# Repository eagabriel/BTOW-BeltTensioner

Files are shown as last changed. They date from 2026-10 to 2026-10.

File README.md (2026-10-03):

# BTOW — Belt Tensioner for iRacing

BTOW turns iRacing acceleration telemetry into independent torque commands for two belts. I built it around two BLDC motors, MT6701 encoders, a modified hoverboard controller and a PC application. The GitHub repository is named BTOW-BeltTensioner.

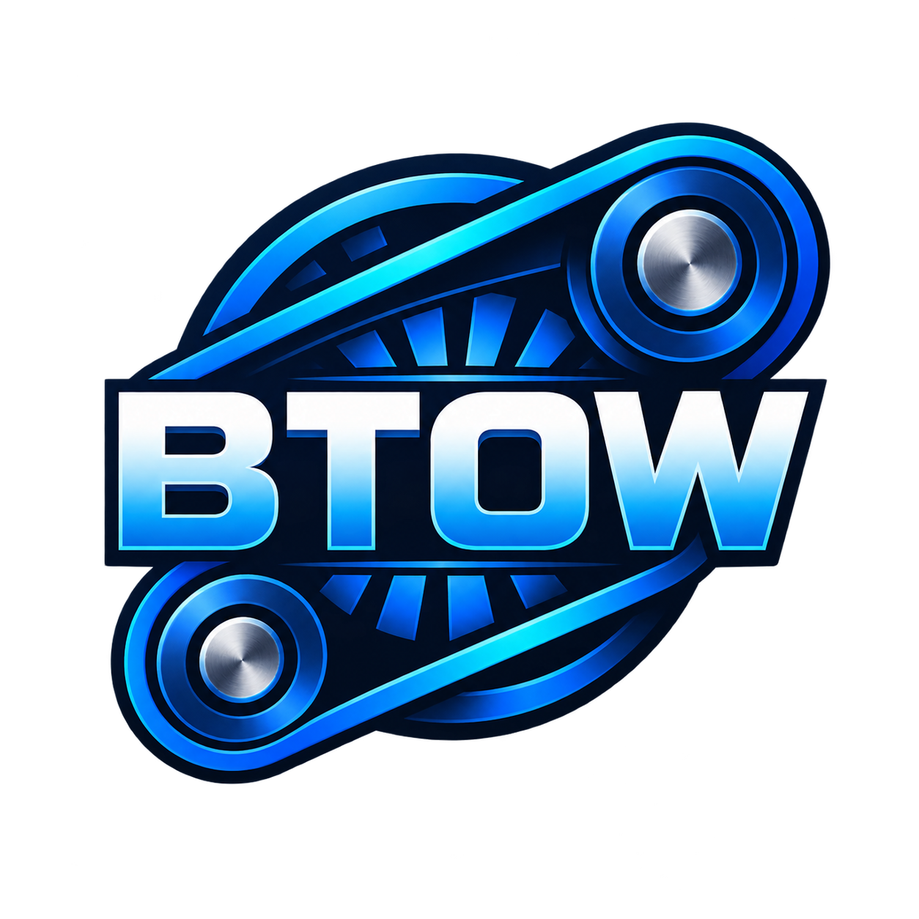
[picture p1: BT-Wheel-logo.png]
BT-Wheel


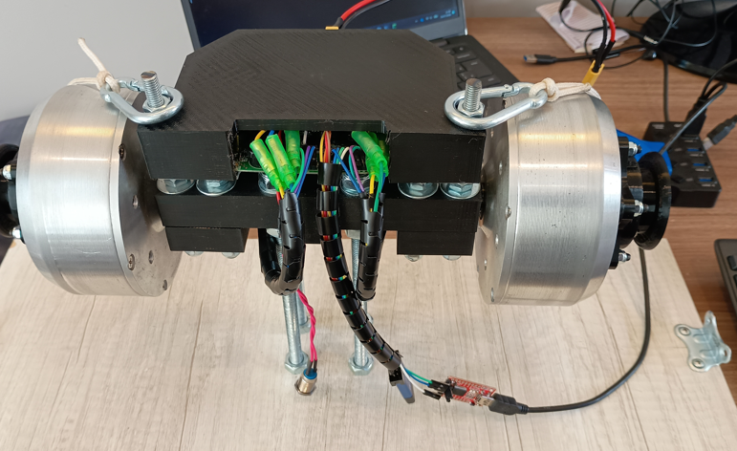
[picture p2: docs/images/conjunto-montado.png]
My assembled BT-Wheel with motors and printed supports


This is my assembly with 3D-printed supports and a cover. Follow the [build and setup tutorial](docs/TUTORIAL.md) for wiring, resistor modifications and software setup. Wire colors in the photos are not a wiring standard.

BT-Wheel is an experimental project, not a certified restraint device. Provide an accessible manual belt release and a physical stop. Software protections do not guarantee release in every failure.

## Belt tensioner in action

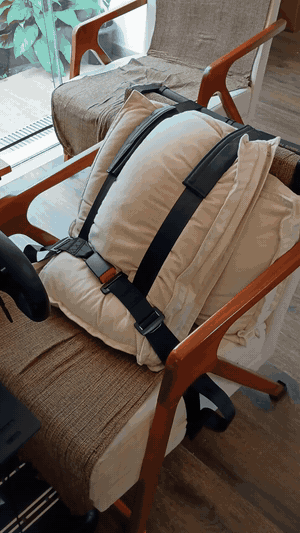
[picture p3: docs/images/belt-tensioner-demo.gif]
BT-Wheel belt tensioner operating — animated demonstration


Watch my belt tensioner operating: [download the demonstration video](https://raw.githubusercontent.com/eagabriel/BTOW-BeltTensioner/refs/heads/main/docs/images/belt-tensioner-demo.mp4) (MP4, approximately 48 MB). Open the downloaded file in your video player; GitHub's file page does not provide inline playback for this video.

## How it works

```text
iRacing → Python / pyirsdk → G mapping → WebSocket → dashboard
                                                      ↓ USB–UART
                            motors ← FOC firmware ← torque commands
```

The backend reads telemetry and calculates torque. The dashboard sends commands through the Web Serial API. The firmware controls current, reads encoders and enforces local limits. Use ST-Link to flash/debug the firmware and a separate USB–UART adapter for PC communication.

Braking adds tension to both belts. Lateral acceleration adds tension to the corresponding side. The vertical effect uses the magnitude of gravity-compensated vertical acceleration. Pretension maintains base tension. Transient belt loosening during acceleration is not implemented.

## Project components

| Component | Purpose |
| --- | --- |
| Python application | Read iRacing, calculate torque and serve the local interface |
| HTML/JavaScript dashboard | Settings, graphs, synthetic tests and serial communication |
| MCU firmware | Dual FOC control, MT6701 feedback, limits and command deadman |
| Compatible hoverboard board | Power stages and current sensing |
| Two BLDC motors and MT6701 encoders | Independent belt actuation |
| Pulleys, belts and frame | Mechanical force transmission |
| Supply and regeneration handling | Supply energy and manage overvoltage |

## Software features

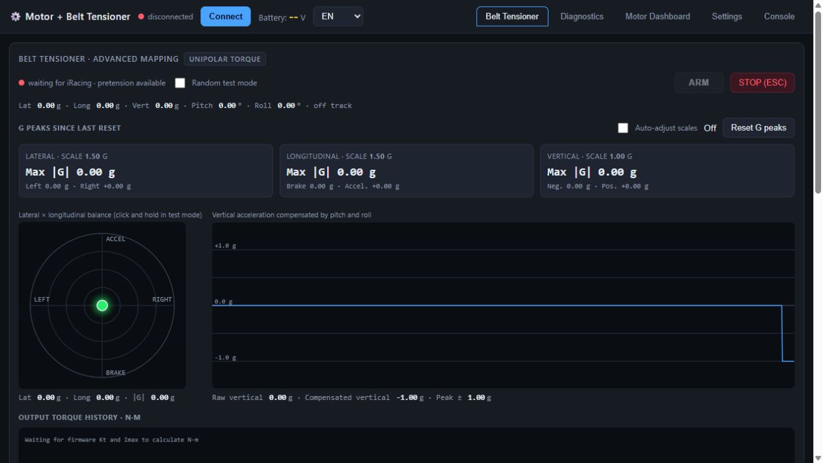
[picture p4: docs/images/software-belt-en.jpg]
BT-Wheel PC dashboard


Select English or Portuguese in the header. Hover over controls for explanations. The [tutorial](docs/TUTORIAL.md) includes real screenshots of settings, motors, diagnostics and the console. Missing readings are expected with serial disconnected.

- Pretension, lateral, longitudinal braking and vertical effects.
- Pitch/roll gravity compensation, dead zones, curves and EMA smoothing.
- Manual/automatic G scales and resettable peak-G tracking.
- Independent attenuation from 100% to 50%, in 1% steps.
- G-ball, vertical history and torque-command history in N·m.
- Automatic JSON settings persistence and separate JSON export/import for motor and belt profiles; board parameters and calibration saved separately in flash.
- Motor dashboard and serial console.
- Individual/bilateral step diagnostics, RAM capture and CSV export.
- MT6701-based RPM limiting and firmware command deadman.

Torque readings are estimates. Command conversion uses `Kt × Imax`; measured current estimates electromagnetic torque. Neither directly measures belt force. Validate belt pull mechanically, accounting for friction, pulley radius and calibration.

## Getting started

Read the [build, installation and usage tutorial](docs/TUTORIAL.md) and the [serial protocol](docs/PROTOCOLO_SERIAL.md).

My working motor and telemetry-effect profiles are included in [profiles/](profiles/). Follow the [profile import instructions](docs/TUTORIAL.md#my-working-example-profiles) and review every hardware limit before using them; they are examples from my assembly, not universal safe defaults.

### Windows executable — no Python required

Open `BTOW.exe` from a compiled distribution. It starts the local server and desktop window, which requires Microsoft Edge WebView2 Runtime. For browser serial access, open `http://127.0.0.1:8000` in Chrome or Edge and keep the executable running. Run only one server instance.

The local build produces `pc-software/dist/BTOW.exe`. Older builds used the name `HoverBelt.exe`. See [GitHub Releases](https://github.com/eagabriel/BTOW-BeltTensioner/releases) for published artifacts. The PC executable does not flash the controller; use ST-Link separately.

Existing settings remain in `%LOCALAPPDATA%\HoverBelt` for compatibility. Use `BTOW_CONFIG_DIR` to override the folder; the older `HOVERBELT_CONFIG_DIR` variable is still supported.

### Python source

Install Python 3.10+ and run from the repository root:

```powershell
cd pc-software
python -m venv .venv
.\.venv\Scripts\python.exe -m pip install -r requirements.txt
.\.venv\Scripts\python.exe run.py
```

Open `http://127.0.0.1:8000` in desktop Chrome or Edge. Serial requires Web Serial API support. The server listens only on the local computer.

To open, build and flash the firmware in **VS Code with PlatformIO IDE**, follow tutorial section 4. Synthetic test mode can move motors when connected and armed.

## Folder layout

```text
BTOW-BeltTensioner/
  pc-software/
    backend/             telemetry, mapping, server and JSON persistence
    frontend/            main dashboard and profile import/export
    assets/              application resources
    tests/               application checks
    app.py               pywebview desktop entry point
    run.py               browser server entry point
    requirements.txt     Python dependencies
    run*.bat             launch scripts
    build*.bat           executable build scripts
  docs/                  tutorial, protocol and images
  firmware/              controller source, drivers and build configuration
    Inc/                 configuration and headers
    Src/                 control loops and drivers
    platformio.ini       TWO_AXIS_VARIANT environment
  mt6701-programmer/      Arduino Pro Micro encoder configuration tool
  Mechanical/            FreeCAD assembly and printed-part designs
  profiles/              working example motor and telemetry-effect JSONs
```

The PC application is contained in `pc-software/`. Launch `run.bat` there, and use `build.bat` or `build-debug.bat` there to package it. Synthetic test mode is available inside the dashboard. Open `firmware/` or `mt6701-programmer/` separately in PlatformIO; each has its own build configuration. Generated caches and executables are excluded from source control.

## Safety and limitations

The firmware requires renewal of `T/TX/TY` within 150 ms; the dashboard has a 250 ms telemetry watchdog. These mechanisms reduce torque in some failures but cannot guarantee mechanical release during every lockup.

Board-temperature monitoring and the dedicated emergency-stop input exist in the code but are disabled in the current configuration. Check the flashed build and wiring before relying on a protection.

## Credits and licensing

I adapted the telemetry signal-conditioning and filtering approach from [mherbold/MarvinsAIRARefactored](https://github.com/mherbold/MarvinsAIRARefactored) for BT-Wheel's belt effects. Credit goes to mherbold and the project's contributors. BT-Wheel applies this processing to independent motor torque commands rather than servo-position commands; it does not reproduce the full application. The referenced project is GPLv3-licensed; this acknowledgment does not replace its applicable license obligations.

The firmware derives from [EFeru/hoverboard-firmware-hack-FOC](https://github.com/EFeru/hoverboard-firmware-hack-FOC) and the [SiMachines fork](https://github.com/SiMachines/hoverboard-firmware-hack-FOC). Preserve their credits and the firmware's GPLv3 license when redistributing it. The application's distribution license still needs to be formalized; this README does not change existing licenses.

Project repository: [eagabriel/BTOW-BeltTensioner](https://github.com/eagabriel/BTOW-BeltTensioner).

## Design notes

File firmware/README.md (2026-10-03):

# BT-Wheel controller firmware

This folder contains the dual-motor controller firmware used by BT-Wheel. The supported PlatformIO environment is `TWO_AXIS_VARIANT`.

Open this folder in VS Code with PlatformIO IDE, or run here:

```powershell
pio run -e TWO_AXIS_VARIANT
```

The output is `.pio/build/TWO_AXIS_VARIANT/firmware.bin`. Upload with ST-Link only after checking the board, MCU support and wiring, with nobody restrained by the belts:

```powershell
pio run -e TWO_AXIS_VARIANT -t upload
```

Both MT6701 encoders must already be configured for PWM. The firmware uses PB6 for the left/Y encoder and PB10 for the right/X encoder, with USART3 remapped to PC10/PC11 for application serial communication.

Follow the [project tutorial](../docs/TUTORIAL.md) for hardware modifications and safety limitations. This firmware is not a certified safety system.

The original fork README is preserved as [UPSTREAM_README.md](UPSTREAM_README.md) for provenance; it is not the current BT-Wheel wiring/setup guide. Preserve the [GPLv3 license](LICENSE), source copyright notices and driver licenses when redistributing this component.

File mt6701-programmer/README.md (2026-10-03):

# MT6701 configurator / EEPROM programmer

Small PlatformIO project targeting a **SparkFun Pro Micro (ATmega32U4, 5 V /
16 MHz variant)**. Purpose: read live angle / field status from an MT6701
magnetic encoder, stage a full output-mode configuration (PWM / ABZ / UVW /
analog + direction + offset), and burn it to the sensor's EEPROM so the DO
pin comes up in the chosen mode on every subsequent power-on — no more MCU-
side runtime configuration needed.

Uses the [`I-AM-ENGINEER/MT6701-arduino`](https://github.com/I-AM-ENGINEER/MT6701-arduino)
library, which is the most complete open-source MT6701 configurator library
(supports every setter plus the EEPROM burn command).

## Why a Pro Micro instead of the STM32 already on the hoverboard board

- EEPROM programming on the MT6701 requires **4.5 V ≤ VDD ≤ 5.5 V**. The
  hoverboard board runs the sensor at 3.3 V; feeding it 5 V there would
  require touching the LDO circuit. A Pro Micro at 5 V handles this
  directly with zero rework on the main board.
- Native USB (ATmega32U4) gives an interactive serial console for typing
  confirmations before an irreversible burn.
- Compact and cheap; can be a dedicated bench tool for programming any
  MT6701 modules that arrive later.

## Wiring — compact "4-in-a-row" layout

All four sensor connections land on adjacent pins between rows 4 and 7 of
the Pro Micro. GND on the right column, SDA/SCL/VDD on the left column,
each in the same horizontal row as the next — you can plug the sensor in
with a 4-wire ribbon and it just works, no crossovers.

```
        USB
    ┌─────────┐
TX0 │ ●     ● │ RAW
RX1 │ ●     ● │ GND
GND │ ●     ● │ RST
GND │ ●     ● │ VCC   ←── swap VDD here temporarily during EEPROM burn
 D2 │ ●     ● │ A3         SDA (D2)
 D3 │ ●     ● │ A2         SCL (D3)
 D4 │ ●     ● │ A1         VDD (D4, soft-5V) ⇄ GND (A1, soft-0V)
 D5 │ ●     ● │ A0
 D6 │ ●     ● │ D15
    ...
```

| Pro Micro pin | MT6701 pin | Role | Driven by |
| --- | --- | --- | --- |
| A1 | GND | Soft-GND (0 V) | `digitalWrite LOW` |
| D2 | SDA | I2C data | Wire library |
| D3 | SCL | I2C clock | Wire library |
| D4 | VDD | Soft-VDD (~4.55 V)  | `digitalWrite HIGH`  |

### Why D4 is used as VDD (and why it's not the whole story)

Purely wiring ergonomics: A1 and D4 are opposite each other on rows 7, and
SDA/SCL are on rows 5/6 right above D4. All four wires plug into one board
edge in physical order (GND, SDA, SCL, VDD from top to bottom). No wire
crossings, no ribbon twists.

`setup()` runs a controlled power-up sequence: enable SDA/SCL pull-ups,
drive A1 LOW (sensor GND), drive D4 HIGH (sensor VDD), wait 50 ms for the
sensor's power-on reset, then bring up I2C.

**Current budget** — this is where the trade-off shows up:

| AVR spec / condition | Number |
| --- | --- |
| Abs-max source/sink per pin | 20 mA |
| VOH @ 20 mA sourcing | ~4.4 V |
| MT6701 typical read/write draw | ~15 mA |
| MT6701 EEPROM burn peak | ~30 mA |

At 15 mA, D4 drops from 5 V to about 4.55 V — comfortably above the
sensor's 3.0 V minimum operating VDD. Read, angle streaming, mode staging
all work fine on soft-VDD.

At 30 mA (burn spikes), D4 sags to ~4.1 V, **below** the 4.5 V EEPROM
programming threshold in the MT6701 datasheet. Burning at that voltage can
silently corrupt the EEPROM.

### Burn procedure with soft-VDD wiring

The `B` command in the console prints an explicit warning and **will not
burn until you type `YES BURN`**. Between the warning and the confirmation:

1. Physically **move the sensor's VDD jumper from D4 to the real VCC pin**
   (right column, 4th pin from USB, labeled `VCC`).
2. Verify with a multimeter that the sensor is now getting 4.8–5.0 V.
3. Then type `YES BURN`, ENTER.

Leave A1 (GND), D2 (SDA), D3 (SCL) untouched.

After the burn completes, you can move VDD back to D4 for further
verification reads. Or just power-cycle everything to confirm the sensor
comes up in the newly-burned default mode.

### Pull-ups: none required for bench use

The ATmega32U4 has internal pull-ups of ~30 kΩ that this sketch explicitly
enables on the I2C pins. At the 100 kHz bus speed configured in `setup()`
with a short jumper cable (<30 cm to the sensor module), the RC rise time
is around 6-7 µs of the 10 µs bit period — marginal but adequate for
one-shot config + burn traffic. Verified sequence:

    C_bus ≈ 100 pF   (short jumper + pin capacitance)
    τ = 30 kΩ × 100 pF = 3 µs
    t_rise ≈ 2.2τ = 6.6 µs

**Constraints to keep the internal pull-ups viable**:

1. Bus speed stays at **100 kHz** (400 kHz will not work — do not raise it
   in code).
2. Cable length **< 30 cm total**. Each extra 10 cm adds ~10 pF.
3. **One sensor at a time.** Two in parallel doubles bus capacitance.
4. Keep the cable clear of EMI sources (no motors nearby — this is a
   quiet bench setup).

If reads look noisy or Wire.endTransmission returns nonzero repeatedly,
solder **4.7 kΩ** externals from each line to 5 V and retry.

**Do NOT connect any other MCU (e.g. the hoverboard STM32) to the sensor
while burning.** Two masters on one I2C bus with different VDDs is a fast
path to a damaged chip.

### Pull-ups: none required for bench use

The ATmega32U4 has internal pull-ups of ~30 kΩ that this sketch explicitly
enables on the I2C pins. At the 100 kHz bus speed configured in `setup()`
with a short jumper cable (<30 cm to the sensor module), the RC rise time
is around 6-7 µs of the 10 µs bit period — marginal but adequate for
one-shot config + burn traffic. Verified sequence:

    C_bus ≈ 100 pF   (short jumper + pin capacitance)
    τ = 30 kΩ × 100 pF = 3 µs
    t_rise ≈ 2.2τ = 6.6 µs

**Constraints to keep the internal pull-ups viable**:

1. Bus speed stays at **100 kHz** (400 kHz will not work — do not raise it
   in code).
2. Cable length **< 30 cm total**. Each extra 10 cm adds ~10 pF.
3. **One sensor at a time.** Two in parallel doubles bus capacitance.
4. Keep the cable clear of EMI sources (no motors nearby — this is a
   quiet bench setup).

If reads look noisy or Wire.endTransmission returns nonzero repeatedly,
solder **4.7 kΩ** externals from each line to 5 V and retry.

**Do NOT connect any other MCU (e.g. the hoverboard STM32) to the sensor
while burning.** Two masters on one I2C bus with different VDDs is a fast
path to a damaged chip.

**Do NOT connect any other MCU (e.g. the hoverboard STM32) to the sensor
while burning.** Two masters on one I2C bus with different VDDs is a fast
path to a damaged chip.

## Build + upload

Requires [PlatformIO CLI](https://platformio.org/install/cli). From this
directory:

```
pio run                     # compile
pio run -t upload           # flash the Pro Micro
pio device monitor          # open the serial console
```

The Pro Micro appears as a USB CDC serial port after upload (may need to
press its reset button once if the bootloader window is missed on the first
upload).

## Console usage

Single-character commands, no ENTER after the command letter itself.
Numbers are prompted separately and terminated by ENTER.

| Key | Action |
| --- | --- |
| `r` | Continuously read + print angle & field status; any key stops |
| `p` | Stage PWM output mode (frequency + polarity) |
| `a` | Stage ABZ (quadrature) mode (pulses per revolution) |
| `n` | Stage analog mode (start & stop angle mapping to 0–100 % of VDD) |
| `u` | Stage UVW (hall emulation) mode (pole pairs) |
| `d` | Toggle direction CW ↔ CCW |
| `o` | Set zero offset in degrees |
| `?` | Print current staged config |
| `B` | Burn EEPROM — irreversible; requires typing `YES BURN` |
| `h` | Print help |

Every setter (`p`, `a`, `n`, `u`, `d`, `o`) applies to the sensor's RAM
immediately, so you can validate the effect with `r` before committing.
Burn writes the current RAM contents to EEPROM.

## Typical workflow to flash the hoverboard sensors to PWM output

1. Power the sensor from the Pro Micro's 5 V rail.
2. Open serial monitor (115200 baud).
3. Confirm sensor is detected — the banner should say
   `MT6701 detected at 0x06.`
4. Rotate shaft by hand, hit `r`, watch angle change smoothly, field = OK.
5. Type `p`, accept the defaults (994.4 Hz, active-high).
6. Verify with a scope on DO — you should see a ~994 Hz square wave whose
   duty cycle changes as you rotate the shaft.
7. Type `d` if the direction needs to be flipped for your mechanical setup.
8. Type `o` and enter the zero-offset (or leave it 0 and offset in firmware).
9. Type `B`, then `YES BURN`, ENTER.
10. Power-cycle the sensor. On next boot the DO pin should default to PWM
    output — no I2C init required.

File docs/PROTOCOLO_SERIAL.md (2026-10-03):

# BTOW serial protocol

USART3: 115200 baud, 8 data bits, no parity, 1 stop bit. ASCII commands end with `\n`. Current pinout: TX PC10, RX PC11.

| Command | Effect |
| --- | --- |
| `T<value>` | Command both motors |
| `TY<value>` | Left/Y command |
| `TX<value>` | Right/X command |
| `E`, `EY`, `EX` | Zero and release manual override on selected axes |
| `S` | Text status |
| `H` | Help |
| `?TLM` | One full telemetry response |
| `CFG DUMP` or `?CFG` | Read configuration |
| `CFG <name>=<value>` | Change an allowed parameter |
| `CFG SAVE` | Persist configuration |
| `CFG SAVE_ALIGN` | Persist alignment when available |
| `CFG RESET` | Defaults in RAM; does not automatically save |
| `DSTART` | Clear and start local capture |
| `DSTOP` | Stop capture |
| `DDUMP` | Download capture; rejected while manual override is active |

`T/TY/TX` accept -32767 to 32767. Belt mapping uses unipolar torque from 0 to 32767. Torque commands do not return an OK for each sample. Renew active axes within 150 ms to avoid the current deadman. If one active axis expires, the firmware zeros both.

## Diagnostic capture

```text
DGHZ 200 COUNT <n>
DGHEADER t,Ycmd,Yapp,Yiq,Yrpm,Xcmd,Xapp,Xiq,Xrpm,flags
DG <t>,<Ycmd>,<Yapp>,<Yiq>,<Yrpm>,<Xcmd>,<Xapp>,<Xiq>,<Xrpm>,<flags>
...
DGE
```

| Field | Unit/meaning |
| --- | --- |
| `t` | Milliseconds since capture started |
| `Ycmd`, `Xcmd` | Requested manual command before physical inversion |
| `Yapp`, `Xapp` | Signed command after inversion/limiting |
| `Yiq`, `Xiq` | FOC current Q4; amperes = raw / 800 |
| `Yrpm`, `Xrpm` | MT6701 RPM Q4; RPM = raw / 16 |
| `flags` | Bitmask below |

| Bit | Value | Meaning |
| --- | --- | --- |
| 0 | 1 | Y limiter |
| 1 | 2 | X limiter |
| 2 | 4 | Valid Y RPM |
| 3 | 8 | Valid X RPM |
| 4 | 16 | Y feedback fault |
| 5 | 32 | X feedback fault |
| 6 | 64 | Deadman |

The buffer holds 512 records and stops when full. Nominal sampling is 200 Hz in the main loop; use timestamps to assess the effective rate. Capture does not change gains or guarantee applied command equals requested command.

## Estimated torque

```text
command torque ≈ command / 32767 × Imax × Kt
electromagnetic torque ≈ Iq [A] × Kt [N·m/A]
```

Account for polarity, calibration, limiting and saturation. Neither formula directly measures mechanical belt pull.

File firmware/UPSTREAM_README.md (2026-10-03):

# Hoverboard Driver FOC Motor Control with Encoder and Brake Resistor Support



This is a fork of the [hoverboard-firmware-hack-FOC](https://github.com/EFeru/hoverboard-firmware-hack-FOC) project that adds AB encoder support and brake resistor functionality for precision motor control applications. 

# *For instructions please check [wiki](https://github.com/SiMachines/hoverboard-firmware-hack-FOC/wiki/Connections)*

For general setup instructions, hardware information, and base firmware features, please refer to the [original repository](https://github.com/EFeru/hoverboard-firmware-hack-FOC).

---

### Key Improvements Over Original Repository

1. **Smooth Torque Output at Zero RPM**

Encoder feedback enables true zero-speed torque control with no cogging or vibration. Perfect for FFB devices like direct drive wheel base, ffb joystick, seatbelts.

2. **PSU Support**

Integrated brake resistor support allows safe operation from bench power supplies. The brake resistor dissipates regenerative energy that would otherwise cause voltage spikes and damage PSUs or trip overvoltage protection.

3. **High-Quality Input Control Performance**

Enhanced PWM input processing (both hardware and software implementations) provides:
- low latency 1000hz polling
- Noise-free
- High Resolution

For information on all improvments see [Pull Request #3](https://github.com/SiMachines/hoverboard-firmware-hack-FOC/pull/3#issue-3584417632).

---

## My Use Case: Direct Drive FFB Wheelbase, FFB Joystick, Seatbelt Tensioner, Rudder Pedals
Wheelbase and Joystick project [Arduino-FFB-wheel](https://github.com/ranenbg/Arduino-FFB-wheel)  by Miloš Ranković

Wheelbase compatible project [OpenFFB](https://github.com/Ultrawipf/OpenFFBoard)  by Yannick Richter 

Any usb controller capable of outputting PWM and Reading ab encoder signals will work, in this case I am using Rane's firmware with arduino pro micro.
For exact wiring connections and components to get check wiki [page](https://github.com/SiMachines/hoverboard-firmware-hack-FOC/wiki/Setup-Arduino%E2%80%90FFB%E2%80%90wheel-(Single-Axis))

https://github.com/user-attachments/assets/64078929-5a0b-43d0-8abf-1ea650a6d936

---

## Quick Start Guide

### 1. Select Your Variant

In `platformio.ini`, uncomment your desired configuration:

```ini
default_envs = ONE_AXIS_VARIANT    ; Single motor with encoder
;default_envs = TWO_AXIS_VARIANT   ; Dual motors with encoders
```

### 2. Essential Configuration

Edit `Inc/config.h` with your specific parameters:

#### Battery Configuration
```c
#define BAT_CELLS               10      // Your battery cell count:
                                        // 6s  = 24V (22.2V - 25.2V)
                                        // 10s = 36V (37V - 42V)
                                        // 13s = 48V (48.1V - 54.6V)
```
### Encoder Configuration

```c
#define ENCODER_X
#define ENCODER_X_PPR              2048     // Your encoder pulses per revolution
#define ALIGNMENT_X_POWER          6553     // Sensor alignment voltage out of 16000 for HW & SW-PWM, out of 1000 for the others
```
#### Internal Brake Resistor 
Uses the left motor driver as a brake resistor (left motor must be disabled).

```c
#define INTBRK_L_EN                         // Enable internal brake on left driver
```
---

## Contributing

Contributions are welcome! Please feel free to submit pull requests or open issues for bugs and feature requests.

---

## License

This project inherits the GPLv3 license from the original [hoverboard-firmware-hack-FOC](https://github.com/EFeru/hoverboard-firmware-hack-FOC) repository.

---

## Support

For issues, please open an issue in this repository.

For general hoverboard firmware questions, refer to the [original repository](https://github.com/EFeru/hoverboard-firmware-hack-FOC) and its wiki.

---

- Original FOC firmware: [EFeru/hoverboard-firmware-hack-FOC](https://github.com/EFeru/hoverboard-firmware-hack-FOC)

---

## Recent Changes (This Fork)

- Added AB quadrature encoder support for precise motor control
- Implemented internal and external brake resistor functionality
- Enhanced PWM input processing (hardware and software)
- Added ADC watchdog handling
- Performance, safety and reliability improvements

For more changes, see [Pull Request #3](https://github.com/SiMachines/hoverboard-firmware-hack-FOC/pull/3#issue-3584417632).

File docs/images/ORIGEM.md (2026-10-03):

# Image sources

Correction, October 3, 2026: the supplied original schematic details `pb10-uart-r-tx-alias.png` and `j7-uart-r-pinout.png` establish PB10/U9 pin 29 → UART_R_TX → R36 (100 Ω) → J7 pin 2. PB11/U9 pin 30 → UART_R_RX → R37 → J7 pin 3. The remapped firmware serial port PC10/PC11 must not be conflated with those historical UART net names.

The assembly photographs and original schematics in this folder document my BT-Wheel build. They are not a universal board pinout.

The `software-*-en.jpg` files are real screenshots captured on October 2, 2026, with English selected, serial disconnected and temporary configuration storage. No motors were armed, tests executed or board settings written. The older Portuguese screenshots are retained but are not used by the English README/tutorial.

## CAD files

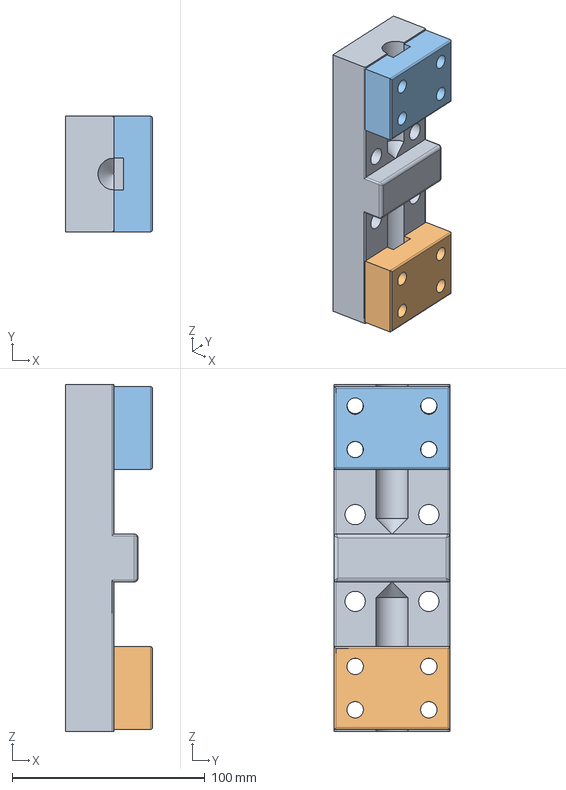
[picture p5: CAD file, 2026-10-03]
Mechanical/HoverBeltTensionerV1.FCStd
45.0 x 60.0 x 180.0 mm
MotorFixBody
MotorFixTableD
MotorFixTableE

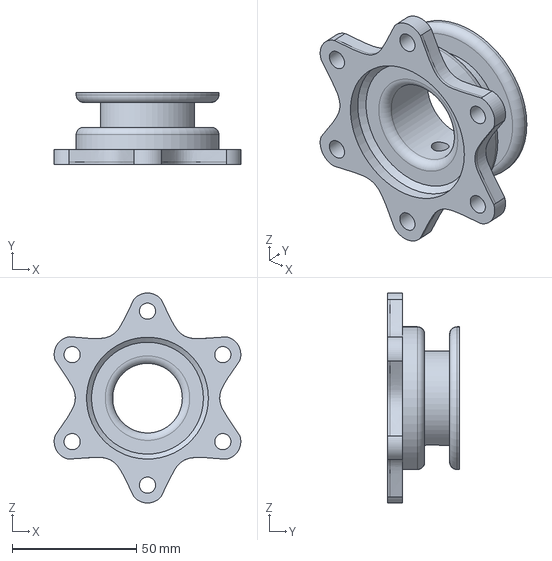
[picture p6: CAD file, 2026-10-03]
Mechanical/Hover_Spacer.FCStd
75.1 x 29.0 x 84.5 mm

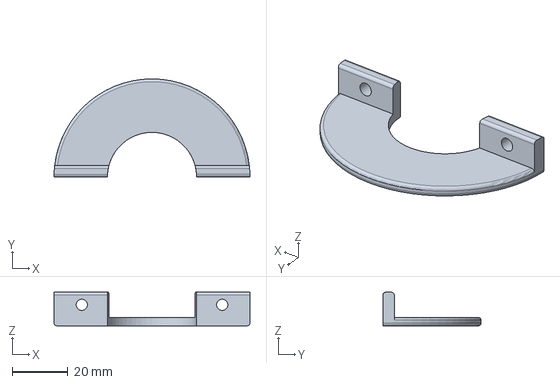
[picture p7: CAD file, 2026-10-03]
Mechanical/BeltGuides.FCStd
70.0 x 35.1 x 12.0 mm

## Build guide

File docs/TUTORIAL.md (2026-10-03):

# Build, configure and use BTOW

This guide covers my build and the software version documented on October 2, 2026. Application and firmware are in separate folders. Match the firmware pinout to your board revision before wiring anything.

## 1. Parts and tools

- A compatible hoverboard controller and MCU configuration.
- Two BLDC motors and two MT6701 encoders configured for PWM. Use the Arduino Pro Micro firmware in `mt6701-programmer` to configure the sensors.
- Encoder magnets and mounts, pulleys, belts and a rigid frame. The FreeCAD mechanical project is in `Mechanical`.
- A compatible 24–36 V supply with suitable regeneration handling.
- ST-Link for SWD programming.
- A USB–UART adapter with 3.3 V logic.
- Windows and desktop Chrome or Edge. Python 3.10+ is needed only for source execution, not the executable.
- PlatformIO, optionally VS Code with PlatformIO IDE.
- iRacing for driving telemetry; synthetic test mode works without it.

My board uses an AT32F403RCT6. PlatformIO declares `genericSTM32F103RC` with `STM32F103RCTx_FLASH.ld`. Check the MCU-specific build define, clock and pinout for your board. The target name alone does not establish compatibility with every board.

### Required: configure both encoders for PWM output

**Both MT6701 encoders must be configured for PWM output before using this controller firmware.** Connecting an encoder does not configure its output mode, and flashing the hoverboard controller does not perform this step. The current firmware reads PWM on PB6 (Y) and PB10 (X), not runtime I2C angle data.

I provide separate **Arduino Pro Micro programming firmware** in the repository's [mt6701-programmer folder](../mt6701-programmer/README.md) to configure the MT6701 for PWM mode. Use its programming instructions and wiring to configure each encoder, then connect its PWM output to the corresponding controller input. Verify PWM feedback on both axes before applying torque.

## 2. Mechanical assembly

Secure motors and printed mounts to the frame. Align and secure magnets and sensors. Guard pinch points and keep belt paths clear of sharp edges. Provide a manual release usable with power off.

My assembled unit with printed supports and cover

The assembled unit with its printed supports and cover. This photograph is not proof of load capacity or safety certification.

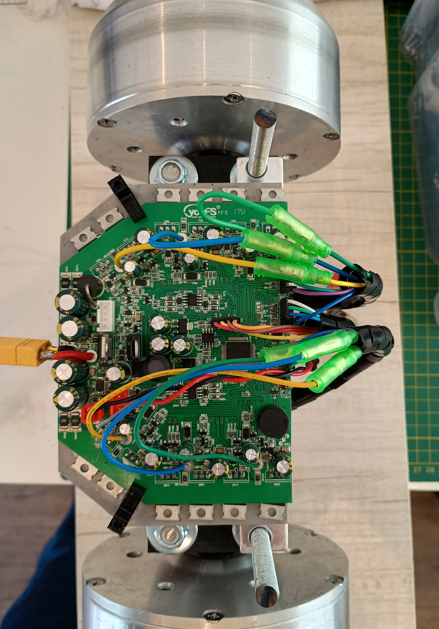
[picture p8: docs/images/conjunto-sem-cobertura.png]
Motors and controller before fitting the cover


My pulley is 38 mm. If this is its **effective diameter**, the radius is 0.019 m:

```text
ideal belt force [N] = torque [N·m] / radius [m]
1 N·m / 0.019 m ≈ 52.6 N
```

This ignores losses and the increasing radius as the belt winds up. There is no universal conversion from vehicle G to force on the driver.

## 3. Wiring and board modifications

### Important: verify hardware modifications on your own board

I mapped the MCU signal connections from the configuration and initialization code in the firmware. This is a reliable reference for the logical pins used by that firmware version; it does not verify the connector routing or components fitted to every board revision. Check that your flashed version uses the same pinout.

**I strongly recommend checking the original schematic against your actual board before changing pull-ups, removing resistors or installing bridges.** The component references and suggested modifications in this guide were reconstructed from photographs, schematics and source code with AI assistance. They may contain identification or interpretation errors and are not guaranteed to be correct for your board.

With power disconnected, verify component references, signal continuity and the supply rail used by each pull-up. Check resistor values and the encoder module's logic levels before soldering. Do not treat an annotated image or an AI-assisted interpretation as a validated electrical design. If the schematic and your board disagree, resolve that difference before modifying or powering the hardware.

| Signal | MCU pin | Connection |
| --- | --- | --- |
| Left/Y MT6701 PWM | PB6 | Y encoder PWM output |
| Right/X MT6701 PWM | PB10 | X encoder PWM output |
| USART3 TX | PC10 | USB–UART RX |
| USART3 RX | PC11 | USB–UART TX |
| Logic ground | GND | Common reference for adapter and sensors |

### Connection overview

Use the original schematics below to trace each MCU pin through its net alias to the physical connector. Earlier AI-edited overview images have been withdrawn from this tutorial because they incorrectly mapped PB10 and J7.

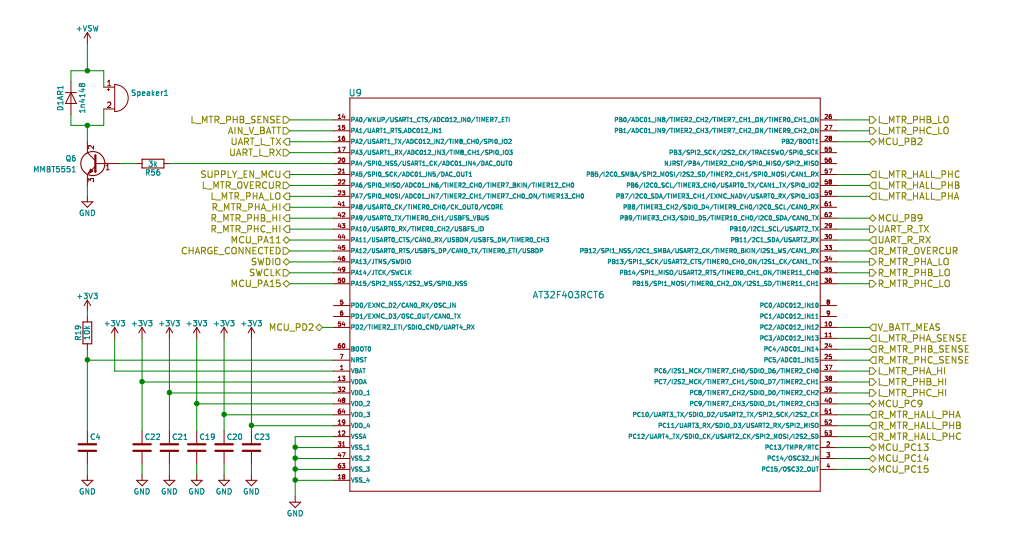
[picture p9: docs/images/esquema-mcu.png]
Original MCU schematic


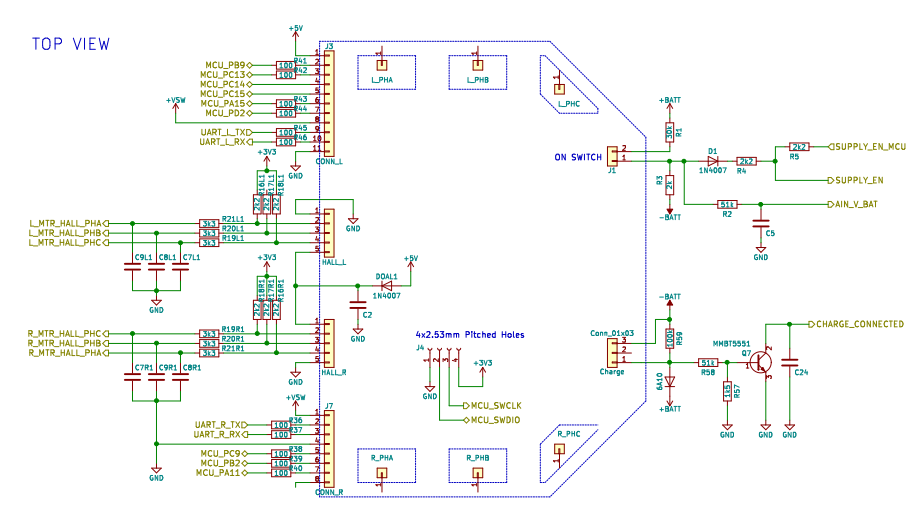
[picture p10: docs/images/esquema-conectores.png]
Original connector and Hall-network schematic


### Series resistors, signal capacitors and pull-ups

In my build, I removed the six **3.3 kΩ series resistors** in the Hall networks and bridged the two pads of each component. The connector schematic labels them R211L, R201L, R191L and R191R, R201R, R211R; reference formatting varies between drawings. A bridge joins the resistor pads; it does **not** short the signal to GND or a supply. Do not apply this change indiscriminately to the UART connectors' 100 Ω resistors.

The external pull-ups are **2.2 kΩ connected to 3.3 V**. The detail below shows R161L/R171L/R181L and R18R1/R17R1/R16R1. Check the populated network on your revision. External resistors and MCU internal pulls are separate things.

**Remove the six signal-to-GND capacitors in the two Hall networks as well.** In the schematic detail below, the left network labels are C9L1, C8L1 and C7L1; the right network labels are C7R1, C9R1 and C8R1. Verify these references against your board revision before removing components. These are the Hall signal-filter capacitors, not the board's power-supply decoupling capacitors.

**Leave capacitor pads open—do not bridge them.** Unlike the series resistors, these capacitors connect each signal to GND; bridging their pads would short the signal to ground. Removing them avoids filtering the encoder PWM edges through these networks. Use the original schematic detail below and the written instructions to verify component references.

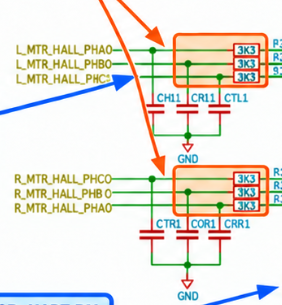
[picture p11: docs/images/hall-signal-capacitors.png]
Hall signal-to-GND capacitors to remove; leave pads open


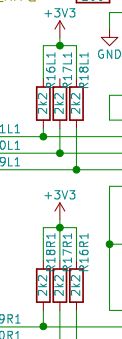
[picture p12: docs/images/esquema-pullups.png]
External 2.2 kΩ pull-ups to 3.3 V


| Schematic point | Firmware use | Notes |
| --- | --- | --- |
| PC10 | Remapped USART3 TX → USB–UART RX | Push-pull output; physical routing must be traced separately, not assumed from UART_R_TX |
| PC11 | Remapped USART3 RX ← USB–UART TX | Internal pull-up enabled; physical routing must be traced separately, not assumed from UART_R_RX |
| J3 UART_L, PA2/PA3 | USART2 disabled in this configuration | Not the application's serial port |
| Left Hall PHC, PB6 | Encoder Y PWM | Internal pull-down enabled |
| U9 pin 29, PB10 → UART_R_TX → R36 (100 Ω) → J7 pin 2 | Encoder X PWM | J7 pin 2 receives the right encoder PWM, despite the historical UART net name |
| U9 pin 30, PB11 → UART_R_RX → R37 (100 Ω) → J7 pin 3 | Not the remapped PC11 serial input | Historical UART net name does not determine current firmware use |

The schematic explicitly routes **PB10 to J7 pin 2 via the UART_R_TX net and R36**. Connect the right encoder PWM to that signal, verifying continuity with power disconnected. A net named UART_R_TX can carry encoder PWM: its name describes the original board function, not the current firmware configuration. Do not confuse the PB10/PB11 UART_R nets with the firmware's remapped PC10/PC11 serial port.

MCU PB10 and PB11 mapped to UART_R_TX and UART_R_RX

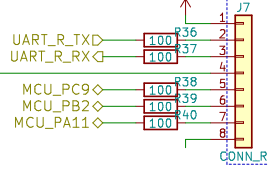
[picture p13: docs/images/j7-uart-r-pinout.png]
J7 pin 2 receives UART_R_TX through R36; pin 3 receives UART_R_RX through R37


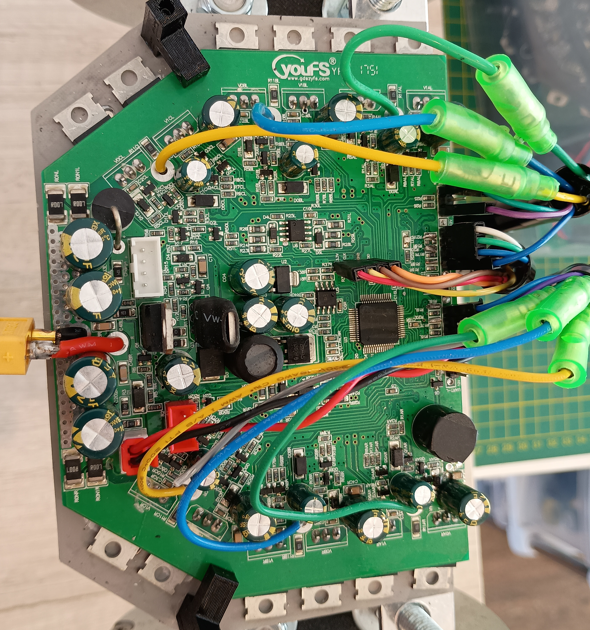
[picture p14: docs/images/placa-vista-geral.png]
Controller and cable overview


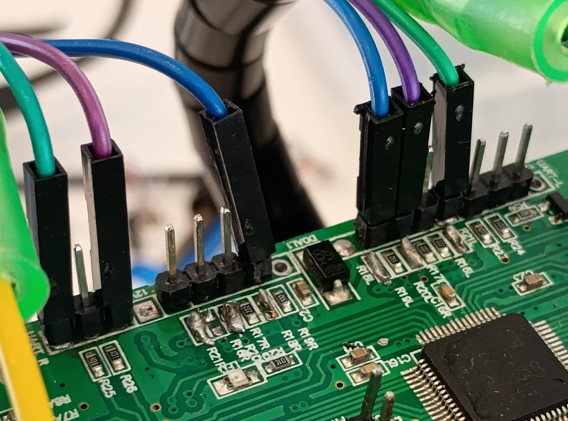
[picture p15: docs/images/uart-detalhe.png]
UART_R and UART_L connectors


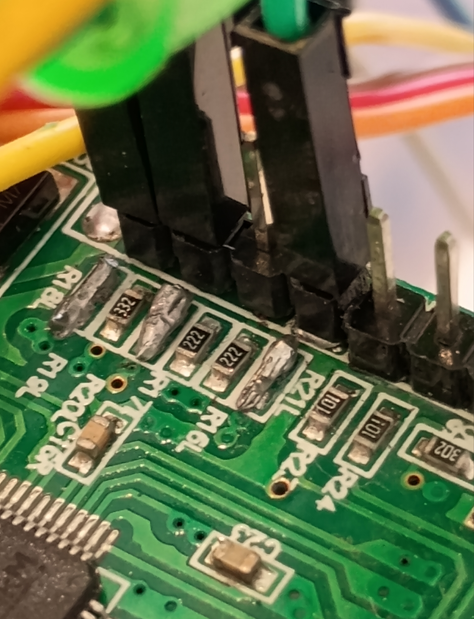
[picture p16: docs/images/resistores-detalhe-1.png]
First resistor and solder-bridge close-up


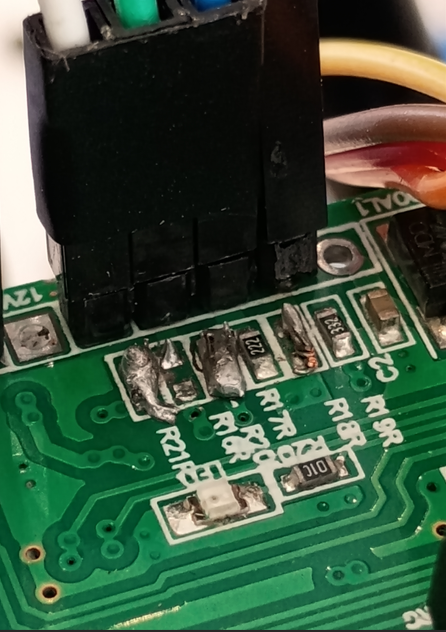
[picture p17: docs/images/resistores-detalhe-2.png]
Second resistor and solder-bridge close-up


The marking `222` means 2.2 kΩ; `101` means 100 Ω. Check bridge continuity and absence of unintended shorts between signals, GND and supplies before powering up. These changes apply to my build, not automatically to every board. Wire colors are not a pinout standard.

USART3 uses partial remapping. Do not use default PB10/PB11 serial wiring: PB10 is the X encoder input. See `Src/setup.c` and `Src/mt6701_pwm.c`.

Keep MCU inputs compatible with 3.3 V logic. Check your MT6701 module's supply and output levels; commercial modules vary. Never connect RS-232 directly or power motor stages from ST-Link/USB–UART.

Connect ST-Link to SWDIO, SWCLK, GND and the appropriate target voltage reference. Identify points by schematic and continuity. Phase, power and braking-resistor wiring must match your board.

## 4. Build and flash the firmware

### Option A — VS Code with PlatformIO IDE

1. Install VS Code and **PlatformIO IDE**. Let tool installation finish and restart if requested.
2. Select **File → Open Folder** and open the repository's `firmware/` folder, containing `platformio.ini`, `Src` and `Inc`.
3. Open the PlatformIO sidebar and wait for project detection.
4. Select **Project Tasks → TWO_AXIS_VARIANT → General → Build**.
5. Confirm `SUCCESS`. The binary is `.pio/build/TWO_AXIS_VARIANT/firmware.bin`.
6. Connect ST-Link, keep everyone out of the belts and make the mechanism safe. Select **Upload** in the same task group to flash and verify.

If VS Code shows **No solution** or no tasks, open the firmware folder, not a single file or the Python application. PlatformIO uses `platformio.ini`, not a `.sln` file. Check the extension is installed and enabled.

### Option B — terminal

From the repository root, enter the firmware folder:

```powershell
cd firmware
pio run -e TWO_AXIS_VARIANT
```

If `pio` is not on PATH, use your local executable:

```powershell
& "$env:USERPROFILE\.platformio\penv\Scripts\platformio.exe" run -e TWO_AXIS_VARIANT
```

Connect ST-Link and make the mechanism safe, then upload:

```powershell
pio run -e TWO_AXIS_VARIANT -t upload
```

### Option C — prebuilt binary, without VS Code

In STM32CubeProgrammer, select ST-Link/SWD, connect, choose the `.bin`, set address `0x08000000`, program and verify. Check programmer support for your MCU. This does not require VS Code or PlatformIO on the flashing PC. Avoid unnecessary full-chip erases: they can remove saved configuration/calibration.

## 5. Install the PC application

Use the executable or Python source. Run only one server instance: both use port 8000.

### Option A — Windows executable, no Python required

1. Obtain `BTOW.exe` from a compiled distribution or check [GitHub Releases](https://github.com/eagabriel/BTOW-BeltTensioner/releases). Local builds produce `pc-software/dist/BTOW.exe`; older builds used the name `HoverBelt.exe`.
2. Copy and open it on your PC. No Python or `pip install` is required.
3. It starts `http://127.0.0.1:8000` and opens a desktop window requiring **Microsoft Edge WebView2 Runtime**.
4. For browser serial access, open the same address in Chrome or Edge and select **Connect**. Keep the executable running.
5. Stop/disarm before closing the application.

The executable does not flash the board; use ST-Link separately. On startup failure, check `btow-error.log` next to the executable. Settings remain under `%LOCALAPPDATA%\HoverBelt` for compatibility with existing installations; renaming the application does not reset profiles.

### Option B — Python source

From the repository root, enter `pc-software/` before installing or running the application:

```powershell
cd pc-software
python -m venv .venv
.\.venv\Scripts\python.exe -m pip install -r requirements.txt
.\.venv\Scripts\python.exe run.py
```

Open `http://127.0.0.1:8000` in Chrome/Edge. Keep the terminal open; `Ctrl+C` stops the server. With `run.bat`, dependencies must be installed in the environment used by `python`.

`app.py` opens the pywebview window. Verify its serial support; use Chrome/Edge for your first connection test.

### Build your executable

With `python` on PATH, run `pc-software/build.bat` (or `build.bat` if already inside `pc-software/`). It installs build dependencies and packages the server/interface using PyInstaller into `pc-software/dist/BTOW.exe`. **It removes existing build and dist folders inside `pc-software/`**: back up wanted artifacts first. The executable runs on another Windows PC without Python, with WebView2 Runtime available. The batch scripts select their own working folder, so launching them by double-click also works.

## 6. Initial configuration and alignment

Select **EN** in the header. Screenshots show the real application with serial disconnected. Empty fields and graphs are not test results; slider defaults are not approved settings for your hardware.

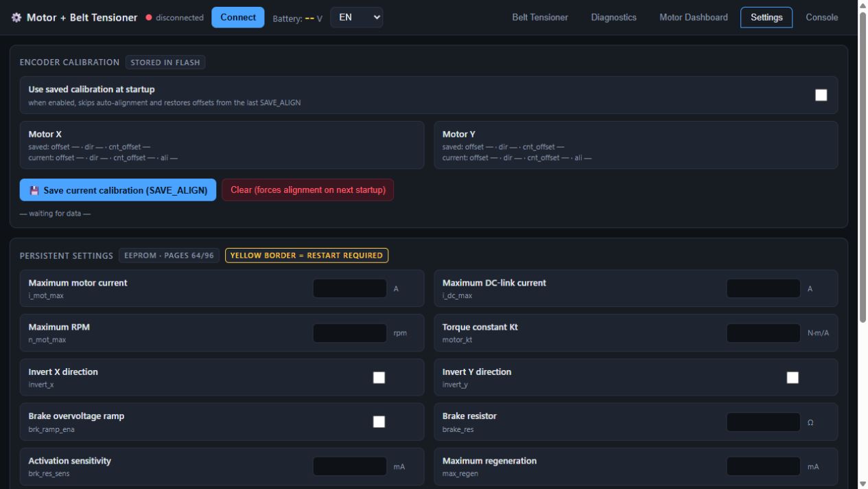
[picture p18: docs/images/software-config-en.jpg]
Settings: calibration and electrical parameters


The upper section contains saved encoder calibration and current, RPM and Kt settings. Electrical values remain empty until received from the board.

1. Keep everyone out of the belts and provide immediate access to stop and power disconnect.
2. Select **Connect** and choose USB–UART. Close other programs using the same COM port.
3. Open **Settings** and select **Reload from board**.
4. Check motor/DC-link current limits, RPM, directions and Kt. Firmware defaults are not automatically safe for your build.
5. Check detection and alignment of both encoders. Alignment can move motors.
6. Use **Save current calibration** only after alignment. Enable saved calibration at boot to reuse offsets.
7. **Apply at runtime** changes RAM; **Apply + save to flash** persists settings. Restart-marked fields take effect after reboot.

Command inversion and encoder electrical alignment are different. Phase, sensor or mechanical changes may require recalibration.

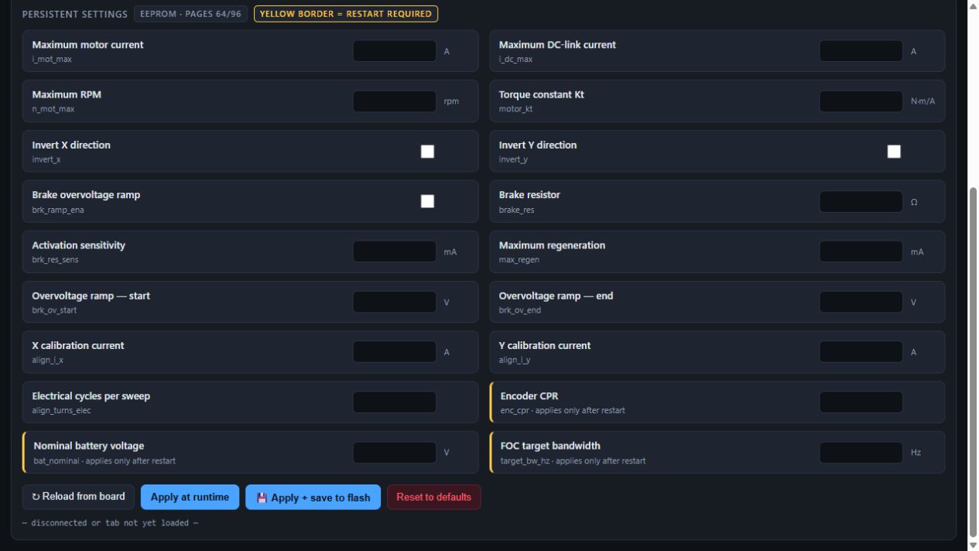
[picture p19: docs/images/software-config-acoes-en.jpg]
Settings: restart-required fields and apply/save actions


Yellow borders identify restart-required fields. Do not use **Reset to defaults** just to refresh the screen.

### Motor readings and communication

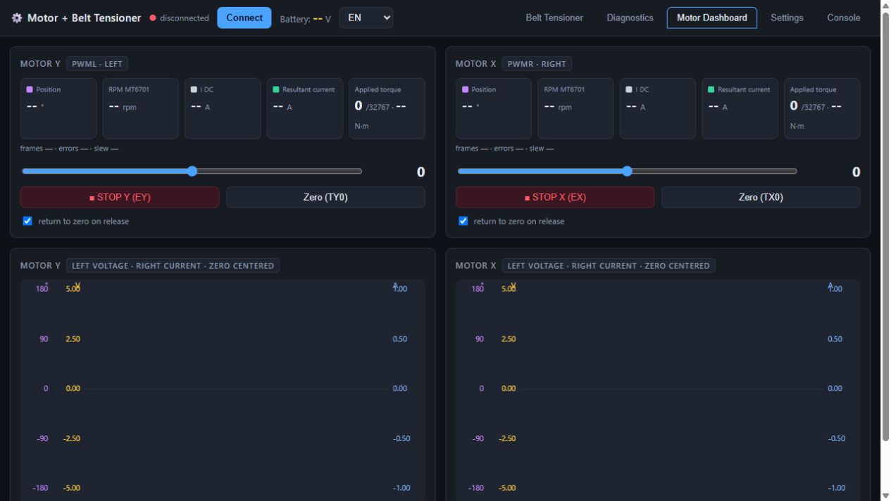
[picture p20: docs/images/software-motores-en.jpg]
Motor Dashboard: independent readings and controls


**Motor Dashboard** shows position, MT6701 RPM, DC current, resultant current and torque. Sliders send real commands when connected; do not explore them with someone in the belts. N·m estimates require Kt and firmware data.

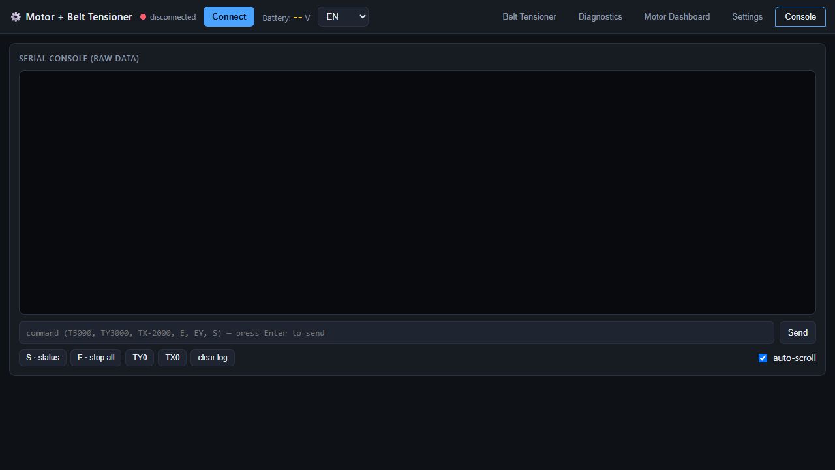
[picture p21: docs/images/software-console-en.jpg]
Console: manual commands and serial log


Use **Console** to inspect messages and send commands. Read the [serial protocol](PROTOCOLO_SERIAL.md) first: torque commands can move motors. This screenshot has an empty log because serial is disconnected.

## 7. Bench tests before iRacing

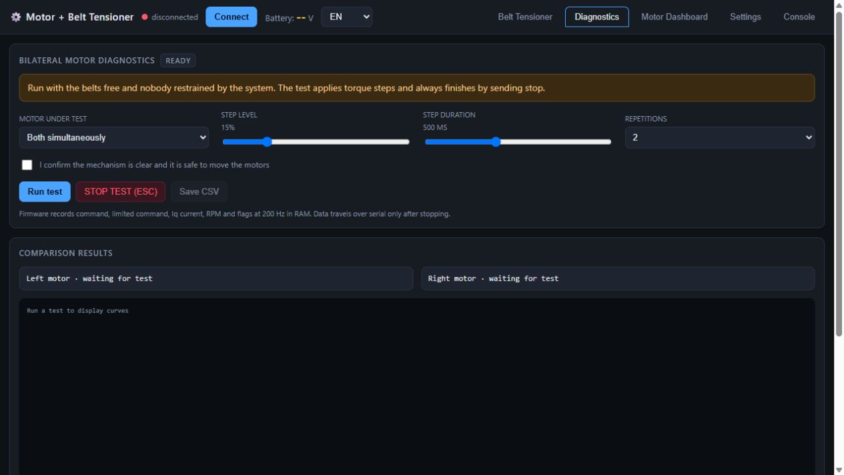
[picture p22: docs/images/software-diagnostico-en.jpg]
Diagnostics: step-test controls


Confirm safe conditions before executing. **Save CSV** becomes available after a capture. The screenshot's 15% and 500 ms are interface defaults, not the first test recommended below.

Start with one motor at a time, 5%, 200 ms and one repetition, a controlled mechanical load and nobody in the belts. Prevent loose belts from whipping; do not rigidly lock the shaft for the first test.

The test renews commands every 50 ms and downloads data after stopping. The RAM buffer holds 512 samples at approximately 200 Hz. Use timestamps for real intervals; the interface rejects sequences exceeding its expected window.

Compare applied command, measured Iq, MT6701 RPM and flags. This is main-loop sampling, not a 16 kHz FOC oscilloscope. Current, rise-time and overshoot summaries are approximations. Use CSV to inspect steps separately and exclude limiter-active intervals.

Conversions: `current [A] = raw / 800`; `MT6701 RPM = raw / 16`. Legacy `n_mot` is not this build's RPM reference.

## 8. Configure belt effects

Belt Tensioner: G monitoring and graphs

The upper section contains source, random test mode, arm/stop, peak G, G-ball and histories. Scroll down for effect settings. Hover over controls for explanations.

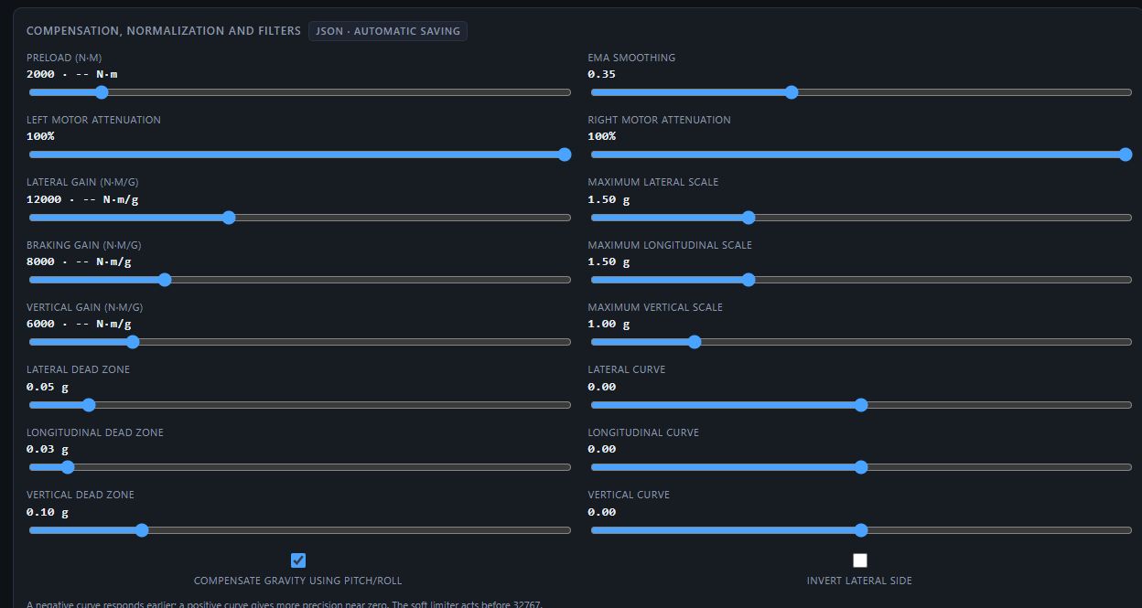
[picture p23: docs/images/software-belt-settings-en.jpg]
Belt effect settings


Without valid telemetry, do not interpret compensated vertical readings as real acceleration. N·m conversion needs Kt/Imax from the firmware.

Start with low pretension/gains. Random mode replaces iRacing with synthetic inputs. It produces **real movement** when connected and armed. Make the mechanism safe before selecting **Arm**.

| Setting | Effect |
| --- | --- |
| Pretension | Base torque on both belts |
| Lateral gain | Additional torque on the corresponding side |
| Braking gain | Bilateral torque for negative longitudinal acceleration |
| Vertical gain | Bilateral torque from vertical magnitude |
| G scale | Acceleration corresponding to full normalized effect |
| Curve | Negative responds earlier; zero linear; positive favors stronger inputs |
| Dead zone | Ignore small inputs |
| EMA smoothing | More smoothing adds delay |
| Left/right attenuation | Reduce final commands from 100% to 50% |

N·m/g labels include normalization: the algorithm divides by G scale and applies curves/filtering before gain. They do not imply a constant physical N·m/g relationship over the entire range.

Compare peak G with your scales. Automatic scaling learns above about 32.2 km/h, starts at 1 g, limits growth and decays slowly. It restarts when enabled or entering the track. Use manual scales for repeatable comparisons.

Keep the weaker motor at 100% and attenuate the stronger one. Attenuation does not fix noise, oscillation or calibration errors.

## 9. Use with iRacing

Start iRacing, enter a session and disable random test mode. Verify the source before arming. The current interface allows arming off track: without driving telemetry it applies pretension with a three-second ramp. Returning to the track resumes telemetry-driven effects while armed. **STOP/ESC** disarms; changing tabs interrupts armed control. Do not assume leaving the car releases all tension.

## 10. Settings and backups

### My working example profiles

I include the two profiles I use on my working assembly:

- [Motor settings — btow-motors.example.json](../profiles/btow-motors.example.json).
- [Telemetry belt effects — btow-belt.example.json](../profiles/btow-belt.example.json).

Use them as a reference for a comparable build, not as universal safe defaults. My motor profile uses a 10 A motor-current limit, a 400 rpm speed limit, Kt = 0.551 N·m/A, a 24 V nominal supply and a 3 Ω braking resistor. Verify these settings, DC-link current, regeneration handling and direction against your actual hardware before applying them. The belt profile includes nonzero pretension and substantial gains; start with reduced limits/gains and nobody restrained by the belts.

1. Back up your current motor and belt settings using **Export JSON**. Stop diagnostics, disarm the system and keep the mechanism safe.
2. Connect the controller, open **Settings / Config**, reload from the controller, then use **Import JSON** to load the motor example. Review every field before **Apply + save to flash**, and restart for startup-only parameters.
3. Configure and verify encoder calibration for your own assembly. These profiles do not contain encoder calibration offsets and do not replace your saved calibration.
4. With the server connected, open **Belt Tensioner** and use **Import JSON** to load the belt example. This replaces and automatically saves the effect settings; check the save status. It does not arm the system.
5. Check encoder feedback, current, motor directions and belt pull with nobody in the belts before manually arming. Importing successfully does not validate electrical or mechanical safety.

Belt settings are saved to `%LOCALAPPDATA%\HoverBelt\belt_advanced.json`. `belt_tensioner.json` belongs to the legacy backend mapping. Electrical settings/calibration are stored separately in MCU flash.

To change the JSON folder:

Run this from `pc-software/`, where the virtual environment was created:

```powershell
$env:BTOW_CONFIG_DIR = 'C:\BTOW-config'
.\.venv\Scripts\python.exe run.py
```

Back up JSONs and record board parameters before firmware or mechanical changes.

### Export and import portable profiles

Use **Export JSON** and **Import JSON** separately in the Config and Belt Tensioner tabs. Each download contains one profile type, with a version number. Export includes the currently displayed values, including edits not yet applied; it is not a fresh read from controller flash. In Config, use **Reload from controller** first if you want to back up the controller's current settings.

- **Motor profile:** importing fills the Config fields for review only. Check current, speed, direction and braking settings against your hardware, then use **Apply + save to flash**. Restart the controller for startup-only fields. Saved encoder offsets, directions and the saved-calibration startup switch are deliberately excluded and left unchanged.
- **Belt Tensioner profile:** importing replaces the telemetry-to-torque settings, including gains, pretension, curves, filters, normalization, gravity compensation, left/right attenuation and automatic scaling. The server must be connected; settings are saved to the existing individual JSON file and loaded on the next startup. Check the automatic-save status for errors.

Both imports disarm the belt system and require manual arming afterward. Stop diagnostics before importing. Invalid, incomplete, out-of-range or wrong-type profiles are rejected before settings change. Motor Kt and current limit are stored in the motor profile, so restore both profiles for consistent N·m displays. Test-source selection, arming state and diagnostic results are not configuration profiles and are not restored.

## 11. Troubleshooting

| Symptom | Check |
| --- | --- |
| Serial adapter missing | Driver, compatible browser and available COM port |
| iRacing unavailable | Active session, Python environment and source |
| N·m unavailable | Receive Kt/Imax from controller |
| Zero RPM while moving | MT6701 wiring/configuration and diagnostic firmware |
| Unrealistic current in older diagnostics | Divide raw Iq by 800 |
| Command cutouts | RPM, configured limit and flags |
| One side oscillates | Capture CSV; check sensor, mechanics and calibration before PI tuning |
| Executable closes at startup | Read btow-error.log |

## 12. Safety protections and limits

Firmware command deadman: 150 ms. Dashboard watchdog: 250 ms. The firmware also checks main-loop progress during manual commands. These cannot cover every failure, including lockups preventing protection code from running.

`ENABLE_BOARD_TEMP_SENSOR` and `ESTOP_ENABLE` are disabled in current `config.h`. The proposed emergency input uses PA3 and conflicts with a brake-input option. Provide an accessible mechanical release and suitable physical stop; the screen button does not replace them.

## 13. Telemetry processing credit

I adapted the telemetry signal-conditioning and filtering approach from [mherbold/MarvinsAIRARefactored](https://github.com/mherbold/MarvinsAIRARefactored). Thank you to mherbold and the project's contributors for their work. In BT-Wheel, the conditioned telemetry drives independent torque commands for the two motors, rather than servo-position commands. This is an adaptation of the processing approach, not a reproduction of the full application. See the [README's credits and licensing section](../README.md#credits-and-licensing) and the original project's GPLv3 license.

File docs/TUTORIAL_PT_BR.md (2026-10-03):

# BTOW tutorial

The tutorial is now in English: [Build, configure and use BTOW](TUTORIAL.md).

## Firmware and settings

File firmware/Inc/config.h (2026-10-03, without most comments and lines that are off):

#define CONFIG_H
#include "stm32f1xx_hal.h"
#include <math.h>
#define PWM_FREQ            16000     // PWM frequency in Hz / is also used for buzzer
#define DEAD_TIME              48     // PWM deadtime
#define DELAY_IN_MAIN_LOOP    5       // [ms] main-loop tick. Do not touch unless you know what you are doing.
#define TIMEOUT                20     // number of wrong / missing input commands before emergency off
#define A2BIT_CONV             50     // A to bit for current conversion on ADC. Example: 1 A = 50, 2 A = 100, etc
#define MANUAL_CMD_TIMEOUT_MS 150U    // streamed T/TX/TY must be renewed before this deadline
#define MANUAL_CMD_TIMEOUT_TICKS ((PWM_FREQ * MANUAL_CMD_TIMEOUT_MS + 999U) / 1000U)
_Static_assert(MANUAL_CMD_TIMEOUT_TICKS > 0U, "Manual-command deadman timeout must be positive");
#define ADC_CONV_TIME_1C5       (14)  //Total ADC clock cycles / conversion = (  1.5+12.5)
#define ADC_CONV_TIME_7C5       (20)  //Total ADC clock cycles / conversion = (  7.5+12.5)
#define ADC_CONV_TIME_13C5      (26)  //Total ADC clock cycles / conversion = ( 13.5+12.5)
#define ADC_CONV_TIME_28C5      (41)  //Total ADC clock cycles / conversion = ( 28.5+12.5)
#define ADC_CONV_TIME_41C5      (54)  //Total ADC clock cycles / conversion = ( 41.5+12.5)
#define ADC_CONV_TIME_55C5      (68)  //Total ADC clock cycles / conversion = ( 55.5+12.5)
#define ADC_CONV_TIME_71C5      (84)  //Total ADC clock cycles / conversion = ( 71.5+12.5)
#define ADC_CONV_TIME_239C5     (252) //Total ADC clock cycles / conversion = (239.5+12.5)
#define ADC_CONV_CLOCK_CYCLES   (ADC_CONV_TIME_7C5)
#define ADC_CLOCK_DIV           (4)
#define ADC_TOTAL_CONV_TIME     (ADC_CLOCK_DIV * ADC_CONV_CLOCK_CYCLES) // = ((SystemCoreClock / ADC_CLOCK_HZ) * ADC_CONV_CLOCK_CYCLES), where ADC_CLOCK_HZ = SystemCoreClock/ADC_CLOCK_DIV
#define CURRENT_SENSE_OFFSET_INIT             2048
#define CURRENT_SENSE_OFFSET_CAL_SAMPLES      2000U
#define CURRENT_SENSE_OFFSET_CAL_MODE_AVG
#define CURRENT_SENSE_OFFSET_DCL_TRIM         0     // [ADC counts] Left DC-link offset trim added after calibration average
#define CURRENT_SENSE_OFFSET_DCR_TRIM         0     // [ADC counts] Right DC-link offset trim added after calibration average
#define BOARD_VARIANT           0         // change if board with alternate pin mapping
#define GD32F103Rx              1   // define if you are using a GD32F103Rx MCU to set system clock to 108MHz
#define BAT_FILT_COEF           16384       // battery voltage filter coefficient in fixed-point. coef_fixedPoint = coef_floatingPoint * 2^16. In this case 16384 = 0.25 * 2^16
#define BAT_CALIB_REAL_VOLTAGE  3970      // input voltage measured by multimeter (multiplied by 100). In this case 43.00 V * 100 = 4300
#define BAT_CALIB_ADC           1492      // adc-value measured by mainboard (value nr 5 on UART debug output)
#define BAT_ADC_TO_CV(adc)      ((int16_t)((((int32_t)(adc) * BAT_CALIB_REAL_VOLTAGE) + (BAT_CALIB_ADC / 2)) / BAT_CALIB_ADC))
#define BAT_CELLS               6       // battery number of cells. Normal Hoverboard battery: 10s = 36V nominal, 42V full charge. For 36V battery use 10, for 24V use 6, for 48V use 13 etc.
#define BAT_LVL2_ENABLE         0         // to beep or not to beep, 1 or 0
#define BAT_LVL1_ENABLE         0         // to beep or not to beep, 1 or 0
#define BAT_DEAD_ENABLE         1         // to poweroff or not to poweroff, 1 or 0
#define BAT_BLINK_INTERVAL      80        // battery led blink interval (80 loops * 5ms ~= 400ms)
#define BAT_HIGH                (550 * BAT_CELLS * BAT_CALIB_ADC) / BAT_CALIB_REAL_VOLTAGE;
#define BAT_LVL5                (390 * BAT_CELLS * BAT_CALIB_ADC) / BAT_CALIB_REAL_VOLTAGE    // Green blink:  no beep
#define BAT_LVL4                (380 * BAT_CELLS * BAT_CALIB_ADC) / BAT_CALIB_REAL_VOLTAGE    // Yellow:       no beep
#define BAT_LVL3                (370 * BAT_CELLS * BAT_CALIB_ADC) / BAT_CALIB_REAL_VOLTAGE    // Yellow blink: no beep
#define BAT_LVL2                (360 * BAT_CELLS * BAT_CALIB_ADC) / BAT_CALIB_REAL_VOLTAGE    // Red:          gently beep at this voltage level. [V*100/cell]. In this case 3.60 V/cell
#define BAT_LVL1                (350 * BAT_CELLS * BAT_CALIB_ADC) / BAT_CALIB_REAL_VOLTAGE    // Red blink:    fast beep. Your battery is almost empty. Charge now! [V*100/cell]. In this case 3.50 V/cell
#define BAT_DEAD                (330 * BAT_CELLS * BAT_CALIB_ADC) / BAT_CALIB_REAL_VOLTAGE    // All leds off: undervoltage poweroff. (while not driving) [V*100/cell]. In this case 3.37 V/cell
#define HARD_LIM                 1800  //hard 18v lower limit to prevent damage to driver
#define HARD_18V_COUNTS (((HARD_LIM) * BAT_CALIB_ADC + (BAT_CALIB_REAL_VOLTAGE / 2)) / (BAT_CALIB_REAL_VOLTAGE))
#define TEMP_FILT_COEF          655       // temperature filter coefficient in fixed-point. coefFixedPoint = coef_floatingPoint * 2^16. In this case 655 = 0.01 * 2^16
#define TEMP_CAL_LOW_ADC        1655      // temperature 1: ADC value
#define TEMP_CAL_LOW_DEG_C      358       // temperature 1: measured temperature [°C * 10]. Here 35.8 °C
#define TEMP_CAL_HIGH_ADC       1588      // temperature 2: ADC value
#define TEMP_CAL_HIGH_DEG_C     489       // temperature 2: measured temperature [°C * 10]. Here 48.9 °C
#define TEMP_WARNING_ENABLE     0         // to beep or not to beep, 1 or 0, DO NOT ACTIVITE WITHOUT CALIBRATION!
#define TEMP_WARNING            600       // annoying fast beeps [°C * 10].  Here 60.0 °C
#define TEMP_POWEROFF_ENABLE    0         // to poweroff or not to poweroff, 1 or 0, DO NOT ACTIVITE WITHOUT CALIBRATION!
#define TEMP_POWEROFF           650       // overheat poweroff. (while not driving) [°C * 10]. Here 65.0 °C
#define COM_CTRL        0               // [-] Commutation Control Type
#define SIN_CTRL        1               // [-] Sinusoidal Control Type
#define FOC_CTRL        2               // [-] Field Oriented Control (FOC) Type
#define CFG_OPEN_MODE   0               // [-] OPEN mode
#define CFG_VLT_MODE    1               // [-] VOLTAGE mode
#define CFG_SPD_MODE    2               // [-] SPEED mode
#define CFG_TRQ_MODE    3               // [-] TORQUE mode
#define MOTOR_LEFT_ENA                  // [-] Enable LEFT motor.  Comment-out if this motor is not needed to be operational
#define MOTOR_RIGHT_ENA                 // [-] Enable RIGHT motor. Comment-out if this motor is not needed to be operational
#define CTRL_TYP_SEL    FOC_CTRL        // [-] Control type selection: COM_CTRL, SIN_CTRL, FOC_CTRL (default)
#define CTRL_MOD_REQ    CFG_TRQ_MODE    // [-] Control mode request: CFG_OPEN_MODE, CFG_VLT_MODE (default), CFG_SPD_MODE, CFG_TRQ_MODE. Note: CFG_SPD_MODE and CFG_TRQ_MODE are only available for CTRL_FOC!
#define DIAG_ENA        0              // [-] Motor Diagnostics enable flag: 0 = Disabled, 1 = Enabled (default)
#define I_MOT_MAX       15              // [A] Maximum single motor current limit
#define I_DC_MAX        17              // [A] Maximum stage2 DC Link current limit for Commutation and Sinusoidal types (This is the final current protection. Above this value, current chopping is applied. To avoid this make sure that I_DC_MAX = I_MOT_MAX + 2A)
#define I_DCL_POS       20              // [A]    LEFT Positive DC link current protection limit. Above this value, the power stage is disabled.
#define I_DCL_NEG       20              // [A]    LEFT Negative DC link current protection limit. Below this value, the power stage is disabled.
#define I_DCR_POS       20              // [A]    RIGHT Positive DC link current protection limit. Above this value, the power stage is disabled.
#define I_DCR_NEG       20              // [A]    RIGHT Negative DC link current protection limit. Below this value, the power stage is disabled.
#define DCL_HIGH_COUNTS  (2000 + (I_DCL_POS * A2BIT_CONV))  // compile-time left high threshold in ADC counts (nominal offset 2000)
#define DCL_LOW_COUNTS   (2000 - (I_DCL_NEG * A2BIT_CONV))  // compile-time left low threshold in ADC counts (nominal offset 2000)
#define DCR_HIGH_COUNTS  (2000 + (I_DCR_POS * A2BIT_CONV))  // compile-time right high threshold in ADC counts (nominal offset 2000)
#define DCR_LOW_COUNTS   (2000 - (I_DCR_NEG * A2BIT_CONV))  // compile-time right low threshold in ADC counts (nominal offset 2000)
#define N_MOT_MAX       200             // [rpm] Maximum motor speed limit
#define N_POLE_PAIRS    15                //[PP] Number of motor pole pairs: 15 for standard Hoverboard motors
#define FIELD_WEAK_ENA  0               // [-] Field Weakening / Phase Advance enable flag: 0 = Disabled (default), 1 = Enabled
#define FIELD_WEAK_MAX  5               // [A] Maximum Field Weakening D axis current (only for FOC). Higher current results in higher maximum speed. Up to 10A has been tested using 10" wheels.
#define PHASE_ADV_MAX   25              // [deg] Maximum Phase Advance angle (only for SIN). Higher angle results in higher maximum speed.
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

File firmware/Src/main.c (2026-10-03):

/*
* This file is part of the hoverboard-firmware-hack project.
*
* Copyright (C) 2017-2018 Rene Hopf <renehopf@mac.com>
* Copyright (C) 2017-2018 Nico Stute <crinq@crinq.de>
* Copyright (C) 2017-2018 Niklas Fauth <niklas.fauth@kit.fail>
* Copyright (C) 2019-2020 Emanuel FERU <aerdronix@gmail.com>
*
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
* You should have received a copy of the GNU General Public License
* along with this program.  If not, see <http://www.gnu.org/licenses/>.
*/

#include <stdio.h>
#include <stdlib.h> // for abs()
#include "stm32f1xx_hal.h"
#include "defines.h"
#include "setup.h"
#include "config.h"
#include "util.h"
#include "mt6701.h"
#include "mt6701_pwm.h"
#include "BLDC_controller.h"      /* BLDC's header file */
#include "rtwtypes.h"
#include "comms.h"
#include "motor_cfg.h"
#include "speed_limiter.h"



int main(void);

void SystemClock_Config(void);
void verifyClocks(void);

typedef struct {  // Structure for clock diagnostics
  uint32_t sysclk_hz;
  uint32_t hclk_hz;
  uint32_t pclk1_hz;
  uint32_t pclk2_hz;
  uint32_t tim_apb1_hz;
  uint32_t tim_apb2_hz;
} ClockDiagnostics;

volatile ClockDiagnostics g_clockDiag = {0};

//------------------------------------------------------------------------
// Global variables set externally
//------------------------------------------------------------------------
extern TIM_HandleTypeDef htim_left;
extern TIM_HandleTypeDef htim_right;
extern ADC_HandleTypeDef hadc1;
extern ADC_HandleTypeDef hadc2;
extern ADC_HandleTypeDef hadc3;

extern volatile adc_buf_t adc_buffer;

extern UART_HandleTypeDef huart2;
extern UART_HandleTypeDef huart3;

volatile uint8_t uart_buf[200];

// Matlab defines - from auto-code generation
//---------------
extern P    rtP_Left;                   /* Block parameters (auto storage) */
extern P    rtP_Right;                  /* Block parameters (auto storage) */
extern ExtY rtY_Left;                   /* External outputs */
extern ExtY rtY_Right;                  /* External outputs */
extern ExtU rtU_Left;                   /* External inputs */
extern ExtU rtU_Right;                  /* External inputs */
extern DW   rtDW_Left;                  /* Internal states (diagnostic only) */
extern DW   rtDW_Right;
//---------------

extern uint8_t     inIdx;               // input index used for dual-inputs
extern uint8_t     inIdx_prev;
extern InputStruct input1[];            // input structure
extern InputStruct input2[];            // input structure

extern int16_t speedAvg;                // Average measured speed
extern int16_t speedAvgAbs;             // Average measured speed in absolute
extern volatile uint32_t timeoutCntGen; // Timeout counter for the General timeout (PPM, PWM, Nunchuk)
extern volatile uint8_t  timeoutFlgGen; // Timeout Flag for the General timeout (PPM, PWM, Nunchuk)
extern uint8_t timeoutFlgADC;           // Timeout Flag for for ADC Protection: 0 = OK, 1 = Problem detected (line disconnected or wrong ADC data)
extern uint8_t timeoutFlgSerial;        // Timeout Flag for Rx Serial command: 0 = OK, 1 = Problem detected (line disconnected or wrong Rx data)

extern volatile int pwml;               // global variable for pwm left. -1000 to 1000
extern volatile int pwmr;               // global variable for pwm right. -1000 to 1000

extern uint8_t enable;                  // global variable for motor enable

extern int16_t unf_VBUS;                // Calibrated battery voltage sample in V*100 from ISR path
int16_t batVoltage              = 400 * BAT_CELLS;
static int32_t batVoltageFixdt  = (400 * BAT_CELLS) << 16;  // Fixed-point filter starts at 4.00 V/cell in the same centivolt domain as unf_VBUS
int32_t board_temp_adcFixdt = 0;  
int16_t board_temp_adcFilt = 0;


//------------------------------------------------------------------------
// Global variables set here in main.c
//------------------------------------------------------------------------
uint8_t backwardDrive;
extern volatile uint32_t buzzerTimer;
extern uint8_t buzzerFreq;
volatile uint32_t main_loop_counter;
int16_t batVoltageCalib;         // global variable for calibrated battery voltage
int16_t board_temp_deg_c;        // global variable for calibrated temperature in degrees Celsius
int16_t left_dc_curr;            // global variable for Left DC Link current 
int16_t right_dc_curr;           // global variable for Right DC Link current
int16_t dc_curr;                 // global variable for Total DC Link current 
int16_t cmdL;                    // global variable for Left Command 
int16_t cmdR;                    // global variable for Right Command 

//------------------------------------------------------------------------
// Local variables
//------------------------------------------------------------------------


static int16_t    speed;                // local variable for speed. -1000 to 1000
  static int16_t  steer;                // local variable for steering. -1000 to 1000
  static int16_t  steerRateFixdt;       // local fixed-point variable for steering rate limiter
  static int16_t  speedRateFixdt;       // local fixed-point variable for speed rate limiter
  static int32_t  steerFixdt;           // local fixed-point variable for steering low-pass filter
  static int32_t  speedFixdt;           // local fixed-point variable for speed low-pass filter

static uint32_t    buzzerTimer_prev = 0;
static uint32_t    inactivity_timeout_counter;
static uint16_t rate = RATE; // Adjustable rate to support multiple drive modes on startup



int main(void) {

  HAL_Init();
  __HAL_RCC_AFIO_CLK_ENABLE();
  HAL_NVIC_SetPriorityGrouping(NVIC_PRIORITYGROUP_4);
  /* System interrupt init*/
  /* MemoryManagement_IRQn interrupt configuration */
  HAL_NVIC_SetPriority(MemoryManagement_IRQn, 0, 0);
  /* BusFault_IRQn interrupt configuration */
  HAL_NVIC_SetPriority(BusFault_IRQn, 0, 0);
  /* UsageFault_IRQn interrupt configuration */
  HAL_NVIC_SetPriority(UsageFault_IRQn, 0, 0);
  /* SVCall_IRQn interrupt configuration */
  HAL_NVIC_SetPriority(SVCall_IRQn, 0, 0);
  /* DebugMonitor_IRQn interrupt configuration */
  HAL_NVIC_SetPriority(DebugMonitor_IRQn, 0, 0);
  /* PendSV_IRQn interrupt configuration */
  HAL_NVIC_SetPriority(PendSV_IRQn, 0, 0);
  /* SysTick_IRQn interrupt configuration */
  HAL_NVIC_SetPriority(SysTick_IRQn, 0, 0);

  /* Enable the specific fault handlers in SCB so BusFault/UsageFault/MemManage
   * fire their own handlers instead of escalating to a generic HardFault.
   * Also enable trap on divide-by-zero and unaligned access — makes latent
   * bugs surface immediately as UsageFault instead of silent bad data. */
  SCB->SHCSR |= SCB_SHCSR_MEMFAULTENA_Msk
              | SCB_SHCSR_BUSFAULTENA_Msk
              | SCB_SHCSR_USGFAULTENA_Msk;
  SCB->CCR   |= SCB_CCR_DIV_0_TRP_Msk;    /* trap on div-by-zero */

  SystemClock_Config();
  verifyClocks();

  /* SystemClock_Config → HAL_SYSTICK_Config → SysTick_Config resets SysTick
   * priority to the LOWEST (15) via NVIC_SetPriority(..., (1<<__NVIC_PRIO_BITS)-1).
   * That silently defeated our earlier "SysTick=0" set. Force it back to 0 now
   * so SysTick can preempt other priority-0 IRQs like FOC/ADC — otherwise
   * uwTick freezes any time FOC is busy and every HAL_Delay / HAL_UART_Transmit
   * polling loop with a HAL_GetTick-based timeout hangs indefinitely. */
  HAL_NVIC_SetPriority(SysTick_IRQn, 0, 0);

  __HAL_RCC_DMA1_CLK_DISABLE();
  MX_GPIO_Init();
  MX_TIM_Init();
  MX_ADC1_Init();
  MX_ADC2_Init();
  MX_ADC3_Init();
  BLDC_Init();        // BLDC Controller Init

  HAL_GPIO_WritePin(OFF_PORT, OFF_PIN, GPIO_PIN_SET);   // Activate Latch
  HAL_GPIO_WritePin(LED_PORT, LED_PIN, GPIO_PIN_SET);
  Input_Lim_Init();   // Input Limitations Init
  Input_Init();       // Input Init (also runs EE_Init)
  {
    /* Persistent motor configuration — overrides EEPROM legacy slots 1/2 for
     * i_max/n_max with the motor_cfg values, and applies invert/brake/etc. */
    uint8_t cfg_from_eeprom = motor_cfg_init();
    motor_cfg_apply_runtime();
    motor_cfg_apply_stored_alignment();   /* preloads encoder_[xy].ali if align_stored=1 */
    printf("motor_cfg loaded from %s%s\r\n",
      cfg_from_eeprom ? "EEPROM" : "defaults",
      motor_cfg.align_stored ? " (stored alignment restored — auto-align skipped)" : "");
  }
  estop_init();       // E-stop init (noop if disabled)

  HAL_ADC_Start(&hadc1);
  HAL_ADC_Start(&hadc2);
  HAL_ADC_Start(&hadc3);

  #if defined(ENCODER_X) || defined(ENCODER_Y)
  /* Start the MT6701 sampler ~1 kHz. The IRQ guards on encoder.ini so it does
   * nothing until Encoder_X/Y_Init succeeds later in the main loop. */
  MT6701_Sampler_Init();
  #endif

  #if defined(MT6701_MODE_PWM_X)
  /* MT6701 X in PWM output mode — PB10 free-runs on TIM2_CH3 IC. Init the
   * timer once here; sampling is autonomous from now on. See mt6701_pwm.c. */
  MT6701_X_Pwm_Init();
  #endif
  #if defined(MT6701_MODE_PWM_Y)
  /* MT6701 Y in PWM output mode — PB6 free-runs on TIM4_CH1 IC. */
  MT6701_Y_Pwm_Init();
  #endif

  poweronMelody();

  printf("\r\n=== BOOT ===\r\n");
  printf("bat_nominal=%u.%02uV  i_mot_max=%dA  i_dc_max=%dA  n_mot_max=%drpm\r\n",
    motor_cfg.bat_nominal_x100 / 100, motor_cfg.bat_nominal_x100 % 100,
    (int)motor_cfg.i_mot_max, (int)motor_cfg.i_dc_max, (int)motor_cfg.n_mot_max);
  #ifdef BRING_UP_MODE
  printf("BRING_UP_MODE active — bat/DC-link protections disabled\r\n");
  #endif
  #ifdef ENCODER_X
    #if defined(MT6701_MODE_PWM_X)
    printf("ENCODER_X: PWM input capture on PB10 (TIM2_CH3), align_i=%u.%02uA\r\n",
      motor_cfg.align_i_x_x100 / 100, motor_cfg.align_i_x_x100 % 100);
    #else
    printf("ENCODER_X: I2C1 PB6/7 @ %d Hz, align_i=%u.%02uA\r\n",
      (int)MT6701_I2C_CLOCK_HZ,
      motor_cfg.align_i_x_x100 / 100, motor_cfg.align_i_x_x100 % 100);
    #endif
  #else
  printf("ENCODER_X: DISABLED\r\n");
  #endif
  #ifdef ENCODER_Y
    #if defined(MT6701_MODE_PWM_Y)
    printf("ENCODER_Y: PWM input capture on PB6 (TIM4_CH1), align_i=%u.%02uA\r\n",
      motor_cfg.align_i_y_x100 / 100, motor_cfg.align_i_y_x100 % 100);
    #else
    printf("ENCODER_Y: I2C1 PB6/7 @ %d Hz, align_i=%u.%02uA\r\n",
      (int)MT6701_I2C_CLOCK_HZ,
      motor_cfg.align_i_y_x100 / 100, motor_cfg.align_i_y_x100 % 100);
    #endif
  #else
  printf("ENCODER_Y: DISABLED\r\n");
  #endif
  #ifdef SKIP_AUTO_ALIGN
  printf("SKIP_AUTO_ALIGN: alignment will NOT run automatically\r\n");
  #endif
  printf("=============\r\n");
  #if defined(DC_LINK_WATCHDOG_ENABLE)
  DcLinkWatchdog_Init();
  #endif
  
#if defined(ENABLE_BOARD_TEMP_SENSOR)
   board_temp_adcFixdt = adc_buffer.adc12.value.temp << 16;  // Fixed-point filter output initialized with current ADC converted to fixed-point
   board_temp_adcFilt  = adc_buffer.adc12.value.temp;
#endif


  // Loop until button is released (works for GPIO or analog button builds).
  while (powerButtonPressed()) { HAL_Delay(10); }

  
  static uint32_t enc_retry_ts = 0;
  static uint32_t heartbeat_ts = 0;
  static uint8_t  cal_done_prev = 0;

  while(1) {

    /* Throttle encoder (re-)init attempts so a missing MT6701 doesn't burn 3 ms of
     * I2C timeout on every main-loop iteration. 16 ticks/ms -> 8000 ticks = 500 ms. */
    uint8_t encoder_retry_ready = (buzzerTimer - enc_retry_ts) > 8000u;
    if (encoder_retry_ready) {
        enc_retry_ts = buzzerTimer;
    }

    /* Print once when BLDC current-offset calibration completes — signals that
     * FOC current sensing is now trusted and alignment can begin. */
    if (!cal_done_prev && BLDC_CurrentOffsetCalDone()) {
      cal_done_prev = 1;
      printf("[BLDC] current offsets calibrated — alignment can start\r\n");
    }

       #ifdef ENCODER_X
      if (!estop_active()) {
        if (!encoder_x.ini){
          if (encoder_retry_ready) {
            Encoder_X_Init();
          }
        }
        #ifndef SKIP_AUTO_ALIGN
        else if (!encoder_x.ali && BLDC_CurrentOffsetCalDone()) { // Start alignment only after current-offset calibration is complete
          // Run non-blocking encoder alignment
          if (encoder_x.align_state == 0) {
            Encoder_X_Align_Start(); // Start alignment if not already running
          }
          Encoder_X_Align(); // Process alignment state machine
        }
        #endif
      }
    #endif
    #ifdef ENCODER_Y
      if (!estop_active()) {
        if (!encoder_y.ini){
          if (encoder_retry_ready) {
            Encoder_Y_Init();
          }
        }
        #ifndef SKIP_AUTO_ALIGN
        else if (!encoder_y.ali && BLDC_CurrentOffsetCalDone()
              #ifdef ENCODER_X
                && encoder_x.ali        /* wait for X to finish — sequential
                                         * alignment avoids DC-bus/current-sense
                                         * cross-talk that skewed one axis's
                                         * offset when both swept together. */
              #endif
                ) {
          // Run non-blocking encoder alignment
          if (encoder_y.align_state == 0) {
            Encoder_Y_Align_Start(); // Start alignment if not already running
          }
          Encoder_Y_Align(); // Process alignment state machine
        }
        #endif
      }
    #endif
        

    if (buzzerTimer - buzzerTimer_prev > 16*DELAY_IN_MAIN_LOOP) {   // 1 ms = 16 ticks buzzerTimer
    /* MT6701 sampling now runs in TIM7 IRQ at MT6701_SAMPLE_RATE_HZ (~1 kHz).
     * Here we only service deferred I2C bus recovery that the ISR flagged.
     * Recovery is DEBOUNCED to at most once per 20 ms and its log is rate-limited
     * to once per second — motor EMI during alignment can otherwise trigger a
     * flurry of recoveries that fill the TX serial and back up main-loop time. */
    #if defined(ENCODER_X) || defined(ENCODER_Y)
    extern I2C_HandleTypeDef hi2c1;
    extern I2C_HandleTypeDef hi2c2;
    /* buzzerTimer ticks at 16 kHz — see PWM_FREQ. 16 ticks = 1 ms.
     * Debounce was originally 320 (20 ms) sized for HAL_I2C_Init which took
     * that long. FastRecover finishes in <200 µs, so gate recovery only long
     * enough to avoid re-entry from the same IRQ storm — 1 ms is plenty and
     * lets main loop retry every iteration when the bus is bad. Faster
     * recovery cadence directly reduces the encoder-freshness gap the FOC
     * sees during error bursts. */
    #define MT6701_RECOV_DEBOUNCE_TICKS 16u
    #define MT6701_RECOV_PRINT_TICKS   16000u
    #endif
    #if defined(ENCODER_X)
    #if defined(MT6701_BAREMETAL_X)
    /* Bare-metal X recovery. Fast path: I2C2_FastRecover is atomic and takes
     * ~1 µs typical, so we skip the NVIC dance the old HAL_I2C_Init path
     * needed. PE=0 inside the recover blocks IRQ generation for the reset
     * cycle; Kick re-enables ITEVTEN when it starts the next transaction. */
    static uint32_t recov_x_ts       = 0;
    static uint32_t recov_x_print_ts = 0;
    if (MT6701_X_Bare_NeedsRecover() && (buzzerTimer - recov_x_ts) > MT6701_RECOV_DEBOUNCE_TICKS) {
      recov_x_ts = buzzerTimer;
      #if defined(DEBUG_SERIAL_USART2) || defined(DEBUG_SERIAL_USART3)
      if ((buzzerTimer - recov_x_print_ts) > MT6701_RECOV_PRINT_TICKS) {
        recov_x_print_ts = buzzerTimer;
        printf("I2C2 fast-recover X (SR2=0x%04X)\r\n", (unsigned)I2C2->SR2);
      }
      #endif
      I2C2_FastRecover();
      MT6701_X_Bare_ResetState();
    }
    #else
    extern volatile uint8_t mt6701_x_recovery_req;
    extern volatile uint8_t mt6701_x_busy;
    static uint32_t recov_x_ts       = 0;
    static uint32_t recov_x_print_ts = 0;
    if (mt6701_x_recovery_req && (buzzerTimer - recov_x_ts) > MT6701_RECOV_DEBOUNCE_TICKS) {
      mt6701_x_recovery_req = 0;
      recov_x_ts = buzzerTimer;
      /* Silence sampler + I2C IRQs during peripheral reset so no callback fires
       * mid-init and leaves state inconsistent. I2C1_Init re-enables them. */
      HAL_NVIC_DisableIRQ(TIM7_IRQn);
      HAL_NVIC_DisableIRQ(I2C2_EV_IRQn);
      HAL_NVIC_DisableIRQ(I2C2_ER_IRQn);
      #if defined(DEBUG_SERIAL_USART2) || defined(DEBUG_SERIAL_USART3)
      if ((buzzerTimer - recov_x_print_ts) > MT6701_RECOV_PRINT_TICKS) {
        recov_x_print_ts = buzzerTimer;
        printf("I2C2 recover X (SR2=0x%04X errCode=0x%08lX)\r\n",
          (unsigned)I2C2->SR2, (unsigned long)hi2c2.ErrorCode);
      }
      #endif
      I2C_Init();
      mt6701_x_busy = 0;    /* IT transaction (if any) was killed by DeInit path */
      HAL_NVIC_EnableIRQ(TIM7_IRQn);
    }
    #endif  /* MT6701_BAREMETAL_X */
    #endif  /* ENCODER_X */
    #if defined(ENCODER_Y)
    #if defined(MT6701_BAREMETAL_Y)
    /* Bare-metal driver owns Y I2C. Only trigger a full peripheral re-init
     * when its internal watchdog signals a hard bus lockup (state stuck
     * >20 ms) — the state machine itself handles normal AF/OVR/BERR errors
     * inline in the ER IRQ (STOP + back to IDLE). No mt6701_y_busy watchdog,
     * no error-callback debounce — those existed to fight HAL_I2C_Mem_Read_DMA
     * failure modes that don't apply to the bare-metal path. */
    static uint32_t recov_y_ts       = 0;
    static uint32_t recov_y_print_ts = 0;
    if (MT6701_Y_Bare_NeedsRecover() && (buzzerTimer - recov_y_ts) > MT6701_RECOV_DEBOUNCE_TICKS) {
      recov_y_ts = buzzerTimer;
      #if defined(DEBUG_SERIAL_USART2) || defined(DEBUG_SERIAL_USART3)
      if ((buzzerTimer - recov_y_print_ts) > MT6701_RECOV_PRINT_TICKS) {
        recov_y_print_ts = buzzerTimer;
        printf("I2C1 fast-recover Y (SR2=0x%04X)\r\n", (unsigned)I2C1->SR2);
      }
      #endif
      I2C1_FastRecover();
      MT6701_Y_Bare_ResetState();
    }
    #else
    extern volatile uint8_t mt6701_y_recovery_req;
    extern volatile uint8_t mt6701_y_busy;
    static uint32_t recov_y_ts       = 0;
    static uint32_t recov_y_print_ts = 0;
    /* Watchdog: if busy stayed 1 for >100 ms (1600 ticks) without either the
     * Rx-complete or Error callback firing, an IT transaction got stuck
     * (peripheral event never happened). Force recovery so we don't lose the
     * sampler forever. Timestamp is refreshed by the callbacks (set to
     * buzzerTimer any time busy transitions 0→1). */
    extern volatile uint32_t mt6701_y_busy_since;
    if (mt6701_y_busy && (buzzerTimer - mt6701_y_busy_since) > 1600u) {
      mt6701_y_recovery_req = 1;
    }
    if (mt6701_y_recovery_req && (buzzerTimer - recov_y_ts) > MT6701_RECOV_DEBOUNCE_TICKS) {
      mt6701_y_recovery_req = 0;
      recov_y_ts = buzzerTimer;
      HAL_NVIC_DisableIRQ(TIM7_IRQn);
      HAL_NVIC_DisableIRQ(I2C1_EV_IRQn);
      HAL_NVIC_DisableIRQ(I2C1_ER_IRQn);
      #if defined(DEBUG_SERIAL_USART2) || defined(DEBUG_SERIAL_USART3)
      if ((buzzerTimer - recov_y_print_ts) > MT6701_RECOV_PRINT_TICKS) {
        recov_y_print_ts = buzzerTimer;
        printf("I2C1 recover Y (SR2=0x%04X errCode=0x%08lX)\r\n",
          (unsigned)I2C1->SR2, (unsigned long)hi2c1.ErrorCode);
      }
      #endif
      I2C1_Init();   /* re-enables I2C1_EV_IRQn / I2C1_ER_IRQn internally */
      mt6701_y_busy = 0;
      HAL_NVIC_EnableIRQ(TIM7_IRQn);
    }
    #endif  /* MT6701_BAREMETAL_Y */
    #endif  /* ENCODER_Y */

    /* Heartbeat: toggle LED every 500 ms to prove main loop is alive.
     * LED is independent of buzzer — both can run in parallel. */
    if ((buzzerTimer - heartbeat_ts) > 8000u) {
        heartbeat_ts = buzzerTimer;
        HAL_GPIO_TogglePin(LED_PORT, LED_PIN);
    }

    estop_update();                       // E-stop update
    readCommand();                        // Read Command: input1[inIdx].cmd, input2[inIdx].cmd
    calcAvgSpeed();                       // Calculate average measured speed: speedAvg, speedAvgAbs
      // ####### MOTOR ENABLING: Only if the initial input is very small (for SAFETY) #######
        if (enable == 0 && !rtY_Left.z_errCode && !rtY_Right.z_errCode && !estop_active() &&
          ABS(input1[inIdx].cmd) < 50 && ABS(input2[inIdx].cmd) < 50){
        beepShort(6);                     // make 2 beeps indicating the motor enable
        beepShort(4); HAL_Delay(100);
        steerFixdt = speedFixdt = 0;      // reset filters
        enable = 1;                       // enable motors
        printf("-- Motors enabled --\r\n");
      }
     
      // ####### LOW-PASS FILTER #######
      rateLimiter16(input1[inIdx].cmd, rate, &steerRateFixdt);
      rateLimiter16(input2[inIdx].cmd, rate, &speedRateFixdt);
      filtLowPass32(steerRateFixdt >> 4, FILTER, &steerFixdt);
      filtLowPass32(speedRateFixdt >> 4 , FILTER, &speedFixdt);
      steer = (int16_t)(steerFixdt >> 16);  // convert fixed-point to integer
      speed = (int16_t)(speedFixdt >> 16);  // convert fixed-point to integer

        // ####### MIXER #######
        mixerFcn(speed << 4, steer << 4, &cmdR, &cmdL);   // This function implements the equations above


      // ####### SET OUTPUTS (if the target change is less than +/- 100) #######
      #ifdef INVERT_R_DIRECTION
        pwmr = cmdR;
      #else
        pwmr = -cmdR;
      #endif
      #ifdef INVERT_L_DIRECTION
        pwml = -cmdL;
      #else
        pwml = cmdL;
      #endif
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

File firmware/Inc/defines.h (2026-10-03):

/*
* This file is part of the hoverboard-firmware-hack project.
*
* Copyright (C) 2017-2018 Rene Hopf <renehopf@mac.com>
* Copyright (C) 2017-2018 Nico Stute <crinq@crinq.de>
* Copyright (C) 2017-2018 Niklas Fauth <niklas.fauth@kit.fail>
*
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
* You should have received a copy of the GNU General Public License
* along with this program.  If not, see <http://www.gnu.org/licenses/>.
*/

// Define to prevent recursive inclusion
#ifndef DEFINES_H
#define DEFINES_H

#include "stm32f1xx_hal.h"
#include "config.h"
#include "rtwtypes.h" 

#define LEFT_HALL_U_PIN GPIO_PIN_5
#define LEFT_HALL_V_PIN GPIO_PIN_6
#define LEFT_HALL_W_PIN GPIO_PIN_7

#define LEFT_HALL_U_PORT GPIOB
#define LEFT_HALL_V_PORT GPIOB
#define LEFT_HALL_W_PORT GPIOB

#define RIGHT_HALL_U_PIN GPIO_PIN_10
#define RIGHT_HALL_V_PIN GPIO_PIN_11
#define RIGHT_HALL_W_PIN GPIO_PIN_12

#define RIGHT_HALL_U_PORT GPIOC
#define RIGHT_HALL_V_PORT GPIOC
#define RIGHT_HALL_W_PORT GPIOC

#define LEFT_TIM TIM8
#define LEFT_TIM_U CCR1
#define LEFT_TIM_UH_PIN GPIO_PIN_6
#define LEFT_TIM_UH_PORT GPIOC
#define LEFT_TIM_UL_PIN GPIO_PIN_7
#define LEFT_TIM_UL_PORT GPIOA
#define LEFT_TIM_V CCR2
#define LEFT_TIM_VH_PIN GPIO_PIN_7
#define LEFT_TIM_VH_PORT GPIOC
#define LEFT_TIM_VL_PIN GPIO_PIN_0
#define LEFT_TIM_VL_PORT GPIOB
#define LEFT_TIM_W CCR3
#define LEFT_TIM_WH_PIN GPIO_PIN_8
#define LEFT_TIM_WH_PORT GPIOC
#define LEFT_TIM_WL_PIN GPIO_PIN_1
#define LEFT_TIM_WL_PORT GPIOB

#define RIGHT_TIM TIM1
#define RIGHT_TIM_U CCR1
#define RIGHT_TIM_UH_PIN GPIO_PIN_8
#define RIGHT_TIM_UH_PORT GPIOA
#define RIGHT_TIM_UL_PIN GPIO_PIN_13
#define RIGHT_TIM_UL_PORT GPIOB
#define RIGHT_TIM_V CCR2
#define RIGHT_TIM_VH_PIN GPIO_PIN_9
#define RIGHT_TIM_VH_PORT GPIOA
#define RIGHT_TIM_VL_PIN GPIO_PIN_14
#define RIGHT_TIM_VL_PORT GPIOB
#define RIGHT_TIM_W CCR3
#define RIGHT_TIM_WH_PIN GPIO_PIN_10
#define RIGHT_TIM_WH_PORT GPIOA
#define RIGHT_TIM_WL_PIN GPIO_PIN_15
#define RIGHT_TIM_WL_PORT GPIOB
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

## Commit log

2026-10-03 Consolidate BT-Wheel firmware, PC software, encoder tool and documentation
    [BeltGuides.FCStd, HoverBeltTensionerV1.FCStd, Hover_Spacer.FCStd]
2026-10-03 Add animated belt tensioner demo to README
2026-10-03 Credit MarvinsAIRARefactored telemetry conditioning and filtering
2026-10-03 Add working example profiles and safe import instructions
    [btow-motors.example.json]

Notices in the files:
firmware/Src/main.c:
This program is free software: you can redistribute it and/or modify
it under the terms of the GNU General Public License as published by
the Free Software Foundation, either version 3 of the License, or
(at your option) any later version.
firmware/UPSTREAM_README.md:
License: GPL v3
